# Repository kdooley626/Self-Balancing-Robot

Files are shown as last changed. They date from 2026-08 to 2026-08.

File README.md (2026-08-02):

# Self-Balancing Robot — LQR Control on ESP32

A two-wheeled inverted pendulum robot that balances using a complementary-filtered
IMU estimate and a model-based LQR controller.



<!-- A short GIF of it balancing is the single highest-value thing on this page.
     Record a few seconds on your phone, convert to GIF, drop it in assets/. -->

---

## Status

Robot balances using an LQR derived control loop.
Robots x position (horizontal movement) is not controlled, therefore robot "runs away"
and needs to be bumped back and forth to stay in a constrained region.

---

## Hardware

| Component | Part |
| --- | --- |
| MCU | ESP32 DevKit |
| IMU | MPU6050 |
| Motor driver | L298N |
| Motors | TT gearmotors, 1:48 |
| Battery | 6 V pack |

### Pin assignment

| Function | GPIO |
| --- | --- |
| Motor 1 — EN / IN1 / IN2 | 25 / 26 / 27 |
| Motor 2 — EN / IN3 / IN4 | 13 / 32 / 33 |
| I²C — SDA / SCL | 21 / 22 |

### Note on center of mass

---

## State Estimation

Pitch angle is estimated with a complementary filter fusing accelerometer and
gyroscope data:

```
theta = alpha * (theta_prev + gyro_rate * dt) + (1 - alpha) * theta_accel
```

- `alpha = 0.98`, loop rate 100 Hz

- theta_accel angle comes from `atan2` of the gravity vector.

---

## Control Design

### Model

The system is modeled as an inverted pendulum on a driven cart and linearized
about the upright equilibrium.

| Parameter | Symbol | Value |
| --- | --- | --- |
| Body mass | M | 0.10 kg |
| Wheel mass (total) | M_w | 0.07 kg |
| CoM height | L | 0.15 m  |
| Wheel radius | r | 0.033 m |

<!-- Replace with your measured values if these change. -->

### Reduction to two states

The full control model was derived with a four-state state vector: `[x, ẋ, θ, θ̇]`. However,
the motors used for the project do not have encoders, making it difficult to measure x and ẋ.
For this reason the control model was reduced to a two-state state vector: [θ, θ̇].
This was possible because in the state equation the x and ẋ columns of matrix A do not impact θ or θ̇.

One consequence of this is there is nothing preventing the robot from "running away" to balance.
To remedy this, the next step is to add an ultrasonic sensor integrated to the controller with a cascading control loop
in order to keep the robot within a certain distance from a wall or other reference feature while balancing.

### Gains

Solved the ARE with `Q = diag(1, 0.1)`, `R = 1`:  
Q matrix prioritized theta since the primary objective of the robot is to stay upright.  
K = [ -1.047, -0.320 ].
Closed-loop eigenvalues: -3.16, -299.1

### Mapping to motor command

LQR was derived to return a torque value. Therefore the LQR u value was scaled to
a value which could be sent to the motor driver which accepts values in the range 0-255 for the motor speed. One factor for the scale value, is the "stall value"
of the dc motors. Below a certain input speed, the motors do not run at all. Therefore, an adequately large scale value was chosen for the controller, to make sure the resulting
motor inputs exceeded the stall value as the robot tilted small angles. After determining a starting range, the exact value of the scale factor was chosen by trial and error.

```
u = SCALE * (1.047 * theta + 0.320 * theta_dot)
```

## Next Steps

**Cascaded position control.**

Will add an outer control loop using an ultrasonic sensor to maintain a specific distance away from the wall, while balancing

**Controller comparison.**

Will compare robot balancing performance with the control parameters derived from the LQR control method vs parameters tuned from a PID controller

---

## Repository Layout

```
├── Balancing_Control_v1/     # Arduino sketch for LQR controller
├── ControlCode/          # Python LQR solution
├── CAD/              # Chassis stl files (3D printed)
├── Assets/           # Photos and video
└── README.md
```

## Running It

1. Install the `Adafruit_MPU6050` and `Adafruit_Sensor` libraries.
2. Flash `Balancing_Control_v1/` to the ESP32.
3. Hold the robot still through startup — gyro bias calibration runs in `setup()`.
4. Stand it upright and release.

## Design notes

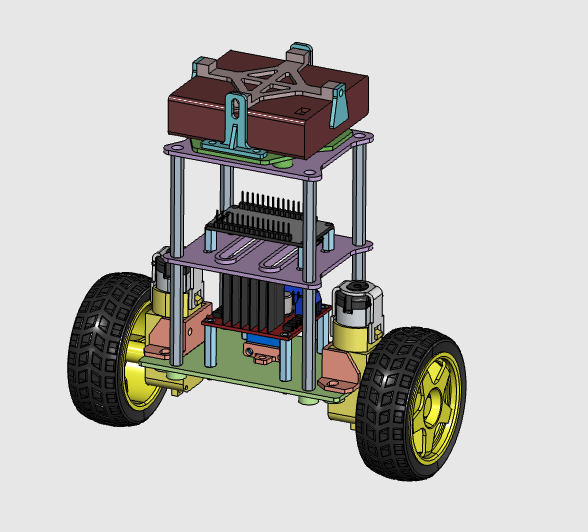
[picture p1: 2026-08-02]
Assets/Full_asssembly_v1.png

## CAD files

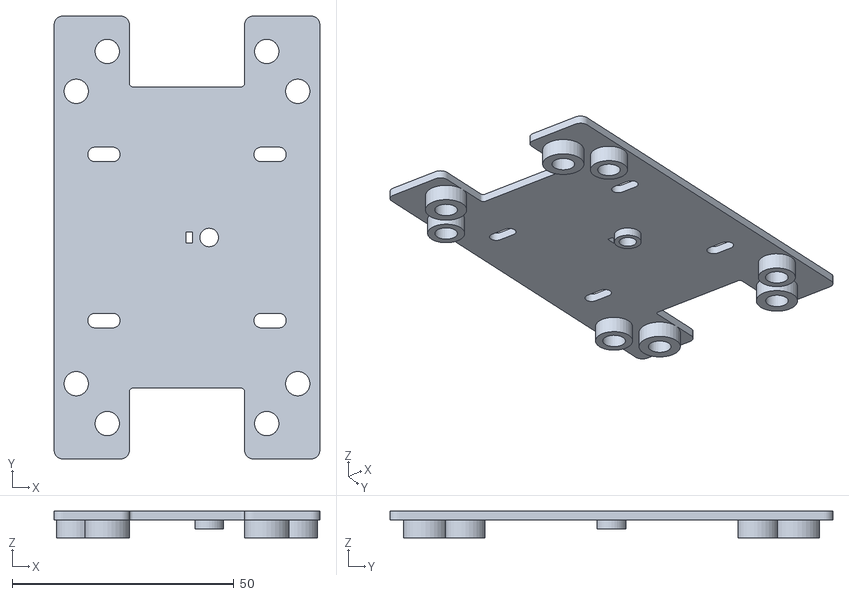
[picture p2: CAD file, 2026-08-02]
CAD/STL/RoboCarLevel1.stl
60.0 x 100.0 x 6.00

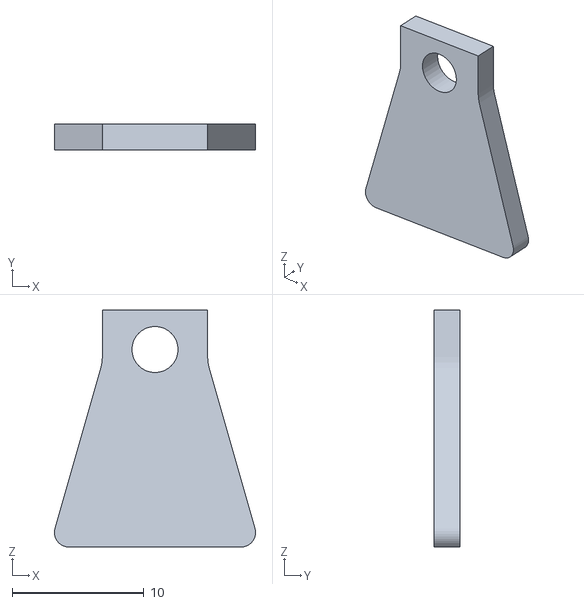
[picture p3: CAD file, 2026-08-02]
CAD/STL/BatteryBracket3.stl
15.3 x 2.00 x 18.0

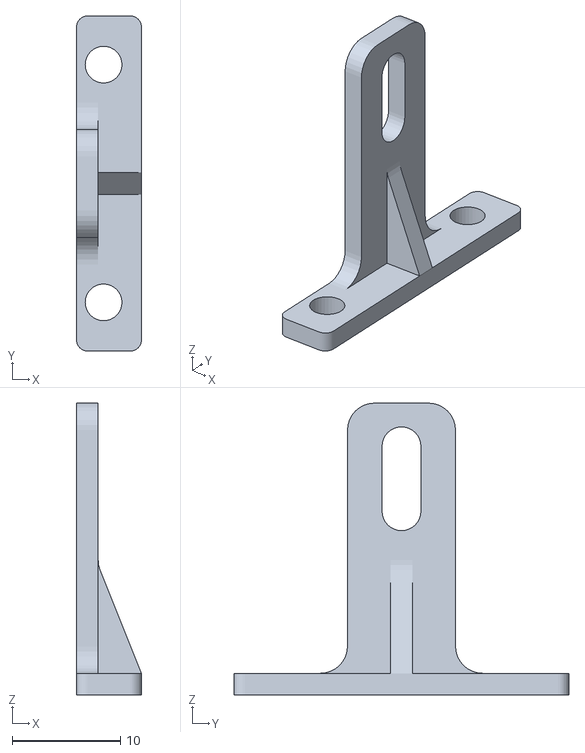
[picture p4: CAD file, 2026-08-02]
CAD/STL/BatteryLid.stl
6.00 x 31.0 x 27.0

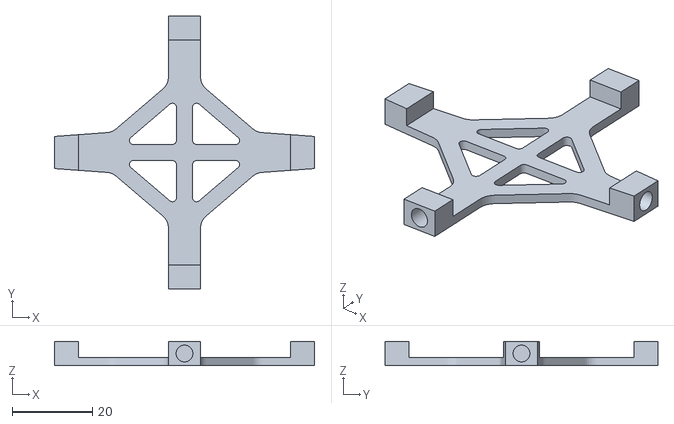
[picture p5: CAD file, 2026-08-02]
CAD/STL/BatteryTop.stl
64.8 x 68.0 x 6.00

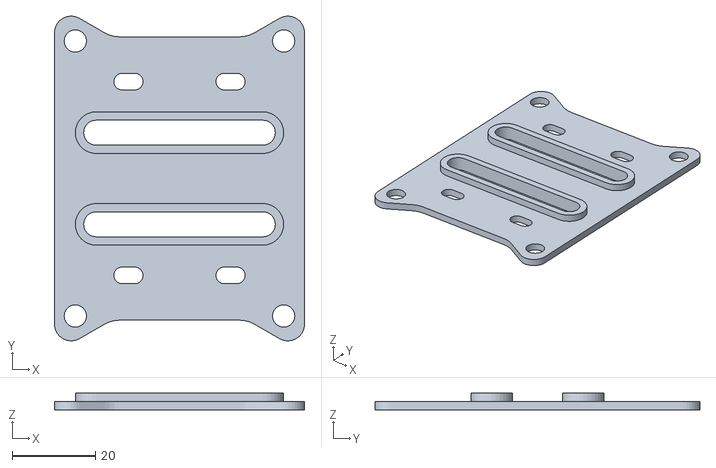
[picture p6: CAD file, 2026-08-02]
CAD/STL/RoboCarLevel2.stl
60.0 x 77.9 x 4.00

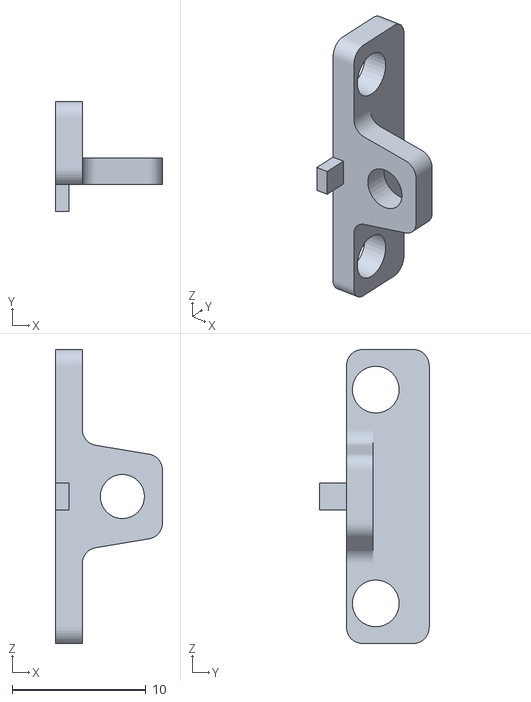
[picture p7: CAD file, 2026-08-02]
CAD/STL/IMU_bracket.stl
8.00 x 8.19 x 22.0

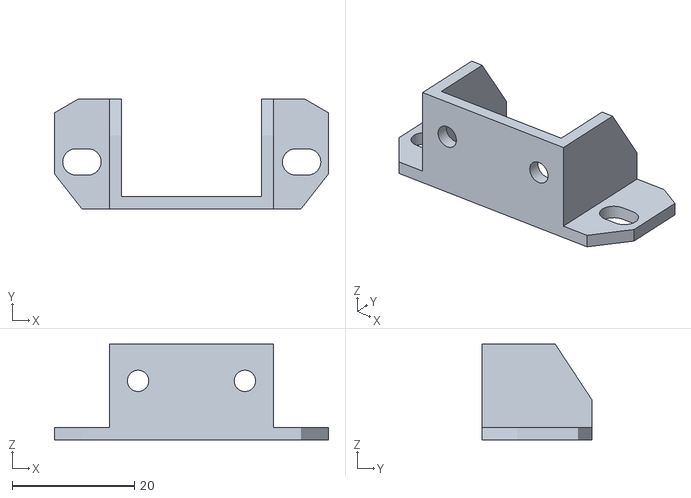
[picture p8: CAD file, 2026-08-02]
CAD/STL/MotorBracketV3.stl
44.9 x 18.0 x 15.7

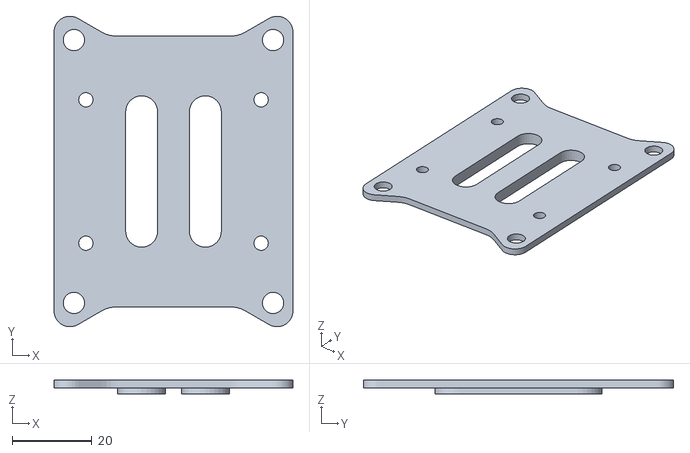
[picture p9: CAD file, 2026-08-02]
CAD/STL/RoboCarLevel3.stl
60.0 x 77.9 x 3.50

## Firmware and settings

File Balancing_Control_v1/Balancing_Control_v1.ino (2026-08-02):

#include <Wire.h>
#include <Adafruit_MPU6050.h>
#include <Adafruit_Sensor.h>

// Set up IMU sensor
// Create instance of the MPU6050 library
Adafruit_MPU6050 mpu;
// Accelerometer angle
float offset = 5.83*PI/180.0;
float gyroDrift = 0;
sensors_event_t a, g, temp;
float failure_angle_deg = 30; // Point at which robot is considered to be past point of rebalancing
float failure_angle_rad = failure_angle_deg*PI/180.0;
bool fail_state = false;

// Set up motors
// Motor 1 pins
const int enable1Pin = 25;
const int motor1Pin1 = 26;
const int motor1Pin2 = 27;

// Motor 2 pins
const int enable2Pin = 13;
const int motor2Pin1 = 32;
const int motor2Pin2 = 33;

// Set PWM properties
const int freq = 5000;
const int pwmChannel = 0;
const int resolution = 8;
int dutyCycle = 200;


// Set up control loop
// Complementary Filter for pitch and roll
float alpha = 0.98; 
const unsigned long time_step = 10000;
// LQR speed constant (to multiply u by because LQR loop gives a motor torque but robot can only control motor speed)
float u_sp = -1500;
int motor_input = 0;

//Declare time variable
unsigned long t0=0;
// float gyro_theta = 0;
// float accel_theta = 0;
float theta0 = 0;
// float theta_filtered = 0;

//Print time variable
unsigned long t_print = 0;
const unsigned long print_step = 50000;

//Declare Gyro struct for integration
struct gyroData {
  float delta_theta;
  unsigned long time;
  float theta_dot;
};

struct FiltData {
  float theta = 0;
  float gyro_theta = 0;
  float accel_theta = 0;
  unsigned long time = 0;
  float theta_dot = 0;
};
// Minimum duty cycle-currently a placeholder
int motor_min = 160;

gyroData gyro_data{};
FiltData current_data{};
void setup() {
  // Set up serial monitor
  Serial.begin(115200);
  delay(1000);
  
  if (!mpu.begin()) {
    Serial.println("MPU6050 not found — check wiring");
    while (1) delay(10);          // halt instead of looping the panic
  }
  Serial.println("MPU6050 ready");
  
   
  // Configure sensor measurement ranges
  mpu.setAccelerometerRange(MPU6050_RANGE_8_G);
  mpu.setGyroRange(MPU6050_RANGE_500_DEG);
  mpu.setFilterBandwidth(MPU6050_BAND_5_HZ);

  gyroDrift = getAverageGyro();

  delay(100);
  // Set up motors
  pinMode(motor1Pin1, OUTPUT);
  pinMode(motor1Pin2, OUTPUT);
  pinMode(enable1Pin, OUTPUT);
  pinMode(motor2Pin1, OUTPUT);
  pinMode(motor2Pin2, OUTPUT);
  pinMode(enable2Pin, OUTPUT);
  // configure LEDC PWM
  ledcAttach(enable1Pin, freq, resolution);
  ledcAttach(enable2Pin, freq, resolution);
 
  // Time variable initiation
  // Get initial time
  t0=micros();
  t_print = micros();
  // initial theta from "previous time step" because there is no previous time step
  mpu.getEvent(&a, &g, &temp);
  theta0 = get_theta();
  fail_state = false;
  current_data.theta = theta0;
  current_data.accel_theta = theta0;
  current_data.gyro_theta = 0;
  

 

}

void loop() {
  if (!fail_state) {
    unsigned long t1 = micros();
    unsigned long delta_t = t1-t0;
    unsigned long delta_tprint = t1-t_print;
    if (delta_t > time_step) {
      current_data = get_filtered(t0, theta0);
      t0 = current_data.time;
      theta0 = current_data.theta;
      // Get motor input
      motor_input = LQR_output(current_data.theta, current_data.theta_dot);
      // Apply motor input to motors
      runMotors(motor_input);
    }
    


    if (delta_tprint > print_step) {
      float theta_filtered_deg = theta0*180.0/PI;
      float theta_gyro_deg = current_data.gyro_theta*180.0/PI;
      float theta_accel_deg = current_data.accel_theta*180.0/PI;

      Serial.print("Theta_Filt:"); Serial.print(theta_filtered_deg); Serial.print(",Theta_Gyro:"); Serial.print(theta_gyro_deg); Serial.print(",Theta_accel:"); Serial.println(theta_accel_deg);
      t_print = micros();

    }
    
   // Failsafe
    if (fabs(theta0)>failure_angle_rad) {
      motorsOff();
      Serial.println("Robot fell.");
      Serial.print("Fall angle: "); Serial.print(theta0*180.0/PI); Serial.println(" degrees");
      //fail_state=true;
    }

  }
  
}
// Function to get all the needed data values for the controls at a given time instant
// Inputs time and theta from previous time step
// Outputs theta, theta_dot, and time of current time step
FiltData get_filtered(unsigned long t_0, float theta_0) {
  FiltData current;
  mpu.getEvent(&a, &g, &temp);
  gyroData gyro_data = get_deltaTheta(t_0);      
  unsigned long t_current=gyro_data.time;
  float gyro_theta = gyro_data.delta_theta+theta_0;
  float accel_theta = get_theta();
  float theta_filtered = alpha*gyro_theta+(1-alpha)*accel_theta;
  current.time = t_current;
  current.theta = theta_filtered;
  current.theta_dot = gyro_data.theta_dot;
  current.gyro_theta = gyro_theta;
  current.accel_theta = accel_theta;
  return current;

}

// Function to be used in control loop
// Runs motors based on the input speed which will be determined by the control loop
void runMotors(int speed) {
  int speed_mag = abs(speed);
  if (speed_mag >= motor_min) {
    if (speed_mag <= 255) {
      ledcWrite(enable1Pin, speed_mag);
      ledcWrite(enable2Pin, speed_mag);
    } else {
      ledcWrite(enable1Pin, 255);
      ledcWrite(enable2Pin, 255);
    }
    if (speed > 0) {
      digitalWrite(motor1Pin1, HIGH);
      digitalWrite(motor1Pin2, LOW);
      digitalWrite(motor2Pin1, LOW);
      digitalWrite(motor2Pin2, HIGH);
    }
    else {
      digitalWrite(motor1Pin1, LOW);
      digitalWrite(motor1Pin2, HIGH);
      digitalWrite(motor2Pin1, HIGH);
      digitalWrite(motor2Pin2, LOW);
    }
  }
  else {
    digitalWrite(motor1Pin1, LOW);
    digitalWrite(motor1Pin2, LOW);
    digitalWrite(motor2Pin1, LOW);
    digitalWrite(motor2Pin2, LOW);
  }
  
}

int LQR_output(float theta, float theta_dot) {
  int output = (int)round(u_sp * (1.047*theta + .32*theta_dot));
  return output;
}

void motorsOff() {
  digitalWrite(motor1Pin1, LOW);
  digitalWrite(motor1Pin2, LOW);
  digitalWrite(motor2Pin1, LOW);
  digitalWrite(motor2Pin2, LOW);
  ledcWrite(enable1Pin, 0);
  ledcWrite(enable2Pin, 0);

}

// Function to get delta theta by multiplying gyro reading by time step 
gyroData get_deltaTheta(unsigned long t0) {
  gyroData data;
  unsigned long t1 = micros();
  float delta_t =(t1-t0)/1000000.0;
  
  float gyro_y = -1.0*g.gyro.y-gyroDrift;
  float delta_theta = gyro_y*delta_t;
  data.delta_theta = delta_theta;
  data.time = t1;
  data.theta_dot = gyro_y;
  return data;
}

float get_theta() {
  
  float xa = a.acceleration.x;
  float  za = a.acceleration.z;
  float theta = atan2(za, -1.0*xa) + offset;
  return theta;
};

void getAverageReading() {
  float total_xa = 0;
  float total_ya = 0;
  float total_za = 0;
  for (int i = 0; i < 10; i++) {
  
    mpu.getEvent(&a, &g, &temp);
    total_xa = total_xa + a.acceleration.x;
    total_ya = total_ya + a.acceleration.y;
    total_za = total_za + a.acceleration.z;
    Serial.print("Accel X: "); Serial.print(a.acceleration.x);
    Serial.print(", Y: "); Serial.print(a.acceleration.y);
    Serial.print(", Z: "); Serial.print(a.acceleration.z);
    Serial.println(" m/s^2");
    delay(100);
  }
 

  float average_xa = total_xa / 10.0;
  float average_ya = total_ya / 10.0;
  float average_za = total_za / 10.0;
  float theta = atan2(average_za, -1.0*average_xa) + offset;
  float theta_deg = theta*180.0/PI;
  float theta_deg_round = round(theta_deg*100)/100.0;
  Serial.println(theta_deg_round);
  
  Serial.print("Average Accel X: "); Serial.print(average_xa);
  Serial.print(", Y: "); Serial.print(average_ya);
  Serial.print(", Z: "); Serial.print(average_za);
  Serial.println(" m/s^2");
}
float getAverageGyro() {
  float total_gy = 0;
  for (int i = 0; i < 100; i++) {
    mpu.getEvent(&a, &g, &temp);
    float gyro_y = -1.0*g.gyro.y;
    total_gy = total_gy + gyro_y;
    float gyro_y_deg = gyro_y*180.0/PI;
    
    
  }
  float average_gy = total_gy / 100.0;
  return average_gy;

};
void runMotor1() {
  ledcWrite(enable1Pin, dutyCycle);
  // put your main code here, to run repeatedly:
  // Move the DC motor forward at max speed
  Serial.println("Moving motor 1 forward");
  digitalWrite(motor1Pin1, HIGH);
  digitalWrite(motor1Pin2, LOW);
  delay(2000);
  // Stop the DC motor
  Serial.println("Motor 1 stopped");
  digitalWrite(motor1Pin1, LOW);
  digitalWrite(motor1Pin2, LOW);
  delay(1000);
}

void runMotor2() {
  ledcWrite(enable2Pin, dutyCycle);
  // put your main code here, to run repeatedly:
  // Move the DC motor forward at max speed
  Serial.println("Moving motor 2 forward");
  digitalWrite(motor2Pin1, LOW);
  digitalWrite(motor2Pin2, HIGH);
  delay(2000);
  // Stop the DC motor
  Serial.println("Motor 2 stopped");
  digitalWrite(motor2Pin1, LOW);
  digitalWrite(motor2Pin2, LOW);
  delay(1000);
}
